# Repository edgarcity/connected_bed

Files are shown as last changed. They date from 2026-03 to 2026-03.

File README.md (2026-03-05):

# Lit Connecté — Réveil intelligent par détection de présence

Système de réveil anti-triche : si je ne suis pas levé 5 minutes après mon alarme, une alarme secondaire se déclenche et continue tant que je suis encore dans le lit. Impossible de tricher — 4 cellules de force sous les pieds du lit mesurent mon poids en continu.

## Comment ça marche

1. L'alarme iPhone sonne → un Raccourci Apple envoie automatiquement une requête HTTP à l'ESP8266
2. L'ESP8266 actionne un relais soudé sur la télécommande du rideau → le rideau se lève
3. Un décompte de 5 minutes démarre en tâche de fond
4. Si je suis encore dans le lit à 5 min → le DFPlayer Mini lance la musique depuis la carte SD
5. La musique s'arrête dès que je me lève

## Matériel

- ESP8266 (serveur web embarqué)
- 4 cellules de force 35 kg + amplificateur HX711
- DFPlayer Mini + carte SD
- Relais soudé sur la télécommande du rideau
- PCB fabriquée et soudée à la main
- Supports imprimés en 3D pour les cellules de force

## Contenu du dépôt

- `docs/` → documentation complète du projet (PDF)
- `code/` → firmware C++ pour ESP8266
- `3D/` → fichiers des pièces imprimées en 3D

## Résultats

- Utilisé quotidiennement, zéro faux positif depuis la mise en service
- Coût total < 35 €
- Intégration iOS native via Raccourci Apple, aucune application tierce

## Licence

[CC BY-NC 4.0](https://creativecommons.org/licenses/by-nc/4.0/) — Utilisation libre et modification autorisées, usage commercial interdit.

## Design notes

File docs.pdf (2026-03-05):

# LIT CONNECTÉ

Réveil intelligent par détection de présence

ESP8266 | Capteur de force | Impression 3D | Domotique | Home Automation

Présentation du projet

Contexte
J’ai deux alarmes sur mon téléphone. La première me réveille. Si je ne suis pas levé de mon lit au bout de 5 minutes, la deuxième alarme (celle du lit) se déclenche et continue de jouer tant que je suis encore couché. Impossible de tricher : les capteurs sous les pieds du lit savent exactement si je suis toujours là.

Solution développée
Quand mon alarme iPhone sonne, un Raccourci Apple envoie automatiquement une requête HTTP à l’ESP8266 qui héberge un serveur web local. Le microcontrôleur reçoit la commande, vérifie via les 4 capteurs de force que je suis bien dans le lit, actionne un relais soudé directement sur les contacts du bouton de la télécommande du rideau pour le lever, puis démarre un décompte de 5 minutes en tâche de fond. Si au bout de ces 5 minutes je suis encore couché, le DFPlayer Mini commence à jouer la musique depuis la carte SD et continue tant que je ne me suis pas levé.

Déroulement d’un réveil
- L’alarme iPhone sonne → le Raccourci Apple envoie la requête HTTP vers l’ESP8266
- L’ESP8266 actionne le relais soudé sur la télécommande du rideau → le rideau se lève
- Décompte de 5 minutes démarre en tâche de fond sur le microcontrôleur
- Levé avant 5 min : les capteurs détectent l’absence de poids → rien ne se passe
- Toujours dans le lit à 5 min : le DFPlayer Mini lance la musique depuis la carte SD
- La musique continue tant que je suis encore couché, s’arrête dès que je me lève

Installation physique

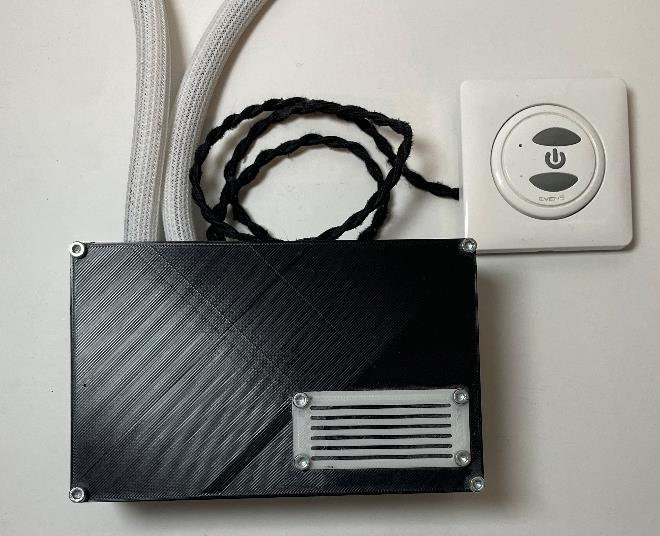
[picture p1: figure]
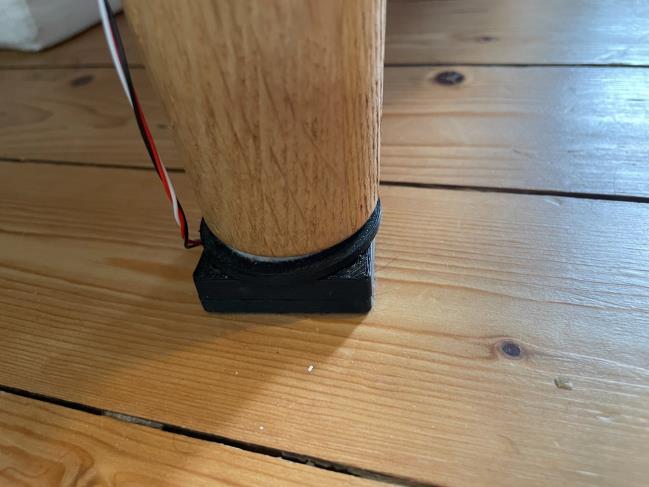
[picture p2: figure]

Boîtier ESP8266 et télécommande du rideau | Support cellule de force sous un pied du lit

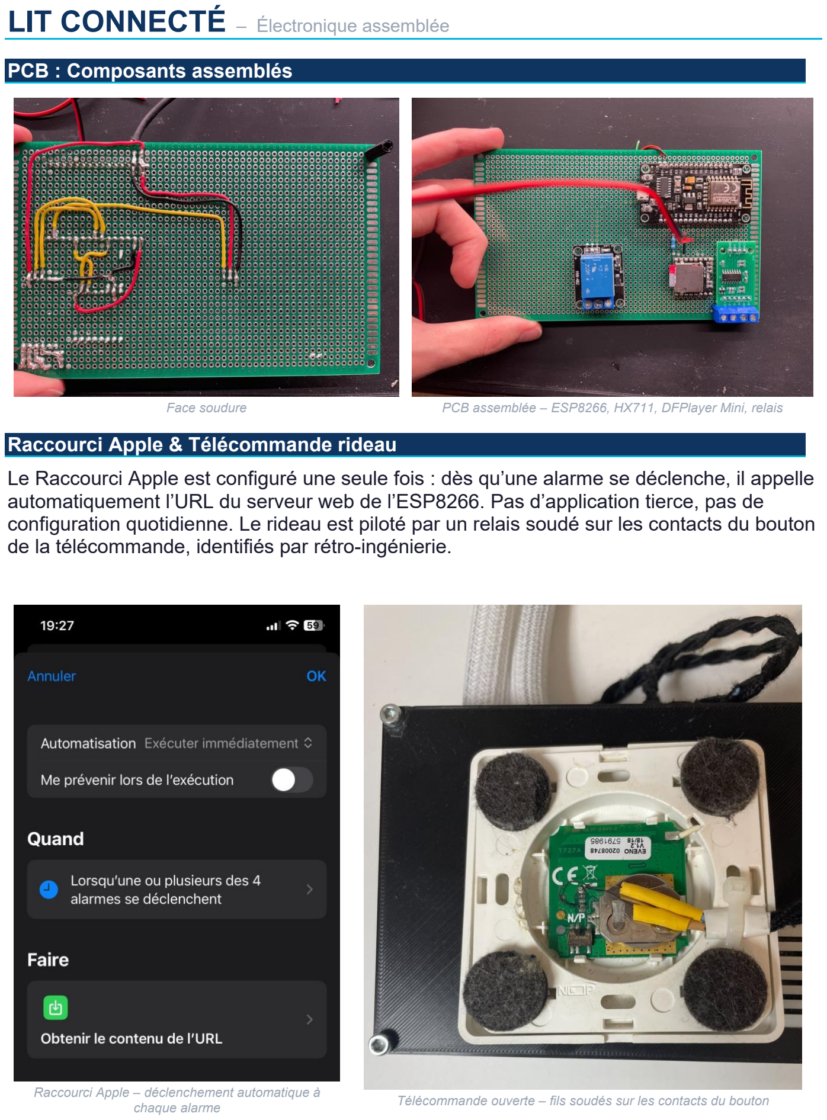
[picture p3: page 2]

LIT CONNECTÉ – Électronique assemblée

PCB : Composants assemblés

Face soudure | PCB assemblée – ESP8266, HX711, DFPlayer Mini, relais

Raccourci Apple & Télécommande rideau

Le Raccourci Apple est configuré une seule fois : dès qu’une alarme se déclenche, il appelle automatiquement l’URL du serveur web de l’ESP8266. Pas d’application tierce, pas de configuration quotidienne. Le rideau est piloté par un relais soudé sur les contacts du bouton de la télécommande, identifiés par rétro-ingénierie.

Raccourci Apple – déclenchement automatique à
chaque alarme | Télécommande ouverte – fils soudés sur les contacts du bouton

LIT CONNECTÉ – Cellules de force & Installation

Le choix du capteur : une décision clé

Le choix du capteur était l'étape la plus critique du projet : un faux négatif et je rate mon réveil, un faux positif et la musique ne tourne pour rien. Le FSR (pastille de pression sous le matelas) était l'option la plus simple, mais sa résistance dérive progressivement et les mouvements pendant le sommeil génèrent trop de bruit. La jauge de contrainte collée sur la structure du lit était plus précise, mais trop sensible aux variations de température et d'humidité pour être fiable sur la durée. La cellule de force s'est imposée : posée sous chaque pied, elle mesure un poids réel en kilogrammes, indépendamment de l'environnement. C'est invasif à l'installation, mais c'est la seule solution qui ne se trompe jamais.

Cellules de force & supports imprimés 3D

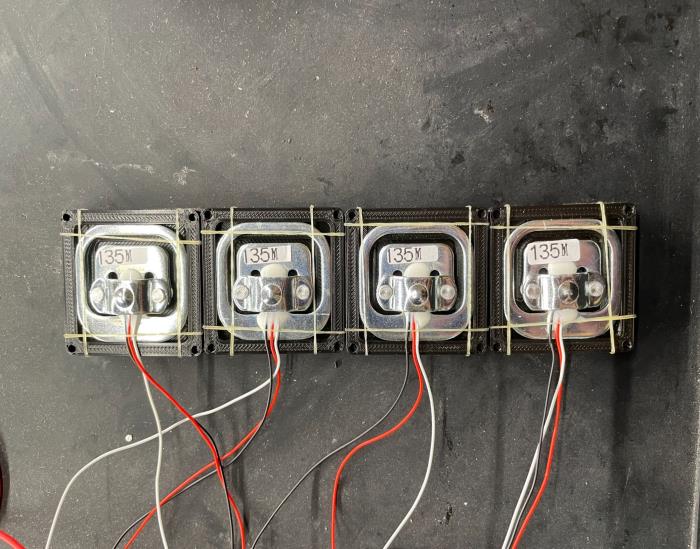
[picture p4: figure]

4 cellules de force 35 kg dans leur support imprimé 3D

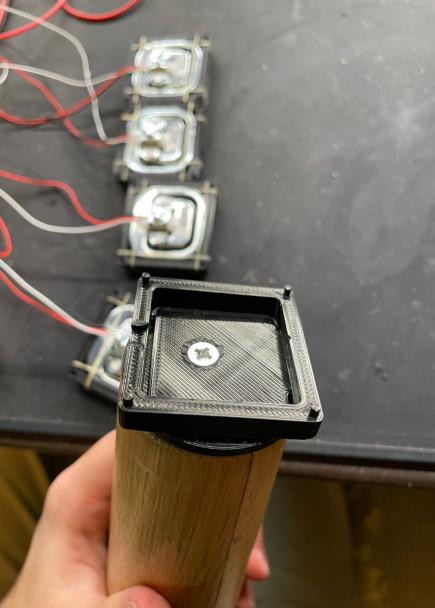
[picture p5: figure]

Support ouvert – logement capteur + vis de fixation

Résultats & Bilan

- Système fonctionnel et utilisé quotidiennement
- 4 cellules de force calibrées sur mon poids : le système ne s’est jamais trompé
- La deuxième alarme ne sonne que si je suis encore dans le lit
- Rideau connecté sans module domotique : relais soudé directement sur la télécommande existante
- Intégration transparente dans iOS : une seule configuration du Raccourci, zéro geste supplémentaire chaque soir
- Coût total < 35 € pour un résultat que les produits commerciaux ne proposent pas
- Compétences mobilisées : firmware C++ sur ESP8266, serveur web embarqué, rétro-ingénierie électronique, CAO & impression 3D, calibration de capteurs

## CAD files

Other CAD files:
3D/boîte de rangement.f3d
3D/capteur boîte.f3d

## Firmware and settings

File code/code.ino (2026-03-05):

#include <ESP8266WiFi.h> 
#include <ESP8266WebServer.h>
#include "HX711.h"
#include <SoftwareSerial.h>
#include <DFRobotDFPlayerMini.h>

// WiFi
const char* ssid = "Reseau YC";
const char* password = "classcroute01";

// Broches
#define RELAIS 5
#define DF_RX  13  // RX du DFPlayer (vers TX ESP8266)
#define DF_TX  2   // TX du DFPlayer (vers RX ESP8266)
#define DOUT 14    // HX711 Data (D5 sur NodeMCU)
#define SCK  12    // HX711 Clock (D6 sur NodeMCU)

// Seuils de poids
#define SEUIL_HAUT 50.0  
#define SEUIL_BAS 30.0   

ESP8266WebServer server(80);
HX711 balance;
SoftwareSerial mp3Serial(DF_RX, DF_TX);  
DFRobotDFPlayerMini dfPlayer;

float facteur_calibration = 11370.0;
float OFFSET_FIXE = 37.98;

unsigned long reveilTimestamp = 0;
bool attente15min = false;
bool musiqueActive = false;
bool surveillanceActive = false;
bool dejaLeve = false;

void handleRequest() {
    if (server.arg("action") == "rotate") {
        server.send(200, "text/plain", "Action effectuée !");
        yield();
        Serial.println("Activation du relais...");

        digitalWrite(RELAIS, HIGH);
        delay(500);
        digitalWrite(RELAIS, LOW);

        reveilTimestamp = millis();
        attente15min = true;  
        dejaLeve = false;
    }
}

void setup() {
    Serial.begin(115200);
    pinMode(RELAIS, OUTPUT);

    WiFi.begin(ssid, password);
    unsigned long wifiTimeout = millis();
    while (WiFi.status() != WL_CONNECTED && millis() - wifiTimeout < 30000) {
        delay(500);
        Serial.print(".");
    }
    if (WiFi.status() == WL_CONNECTED) {
        Serial.println("\nConnecté. IP: " + WiFi.localIP().toString());
    } else {
        Serial.println("\n⚠️ Échec de connexion Wi-Fi !");
    }

    server.on("/", handleRequest);
    server.begin();
    Serial.println("Serveur Web démarré.");

    balance.begin(DOUT, SCK);
    balance.set_scale(facteur_calibration);

    // Init DFPlayer Mini sur les nouvelles broches
    mp3Serial.begin(9600);
    if (!dfPlayer.begin(mp3Serial)) {
        Serial.println("⚠️ Erreur DFPlayer Mini !");
        while (true);
    }
    dfPlayer.volume(20);
}

void loop() {
    server.handleClient();
    
    float poids = (balance.get_units(10) - OFFSET_FIXE);
    Serial.print("Poids mesuré : ");
    Serial.println(poids);

    unsigned long elapsedTime = millis() - reveilTimestamp;

    // Déclenchement après 15 min
    if (attente15min && elapsedTime >= 900000) {  
        Serial.println("⏳ Temps écoulé : Vérification du lit.");
        attente15min = false;

        if (poids > SEUIL_HAUT) {
            musiqueActive = true;
            dfPlayer.loop(1);  // 🔥 Joue le fichier 1 en boucle
            Serial.println("🎵 Tu es encore au lit ! Musique activée.");
        }
    }

    // Arrêt de la musique quand l'utilisateur se lève
    if (musiqueActive && poids < SEUIL_BAS) {
        musiqueActive = false;
        dfPlayer.stop();
        dejaLeve = true;
        reveilTimestamp = millis();
        Serial.println("✅ Tu es levé, musique arrêtée.");
    }

    // Surveillance pendant 1h après le réveil
    if (dejaLeve && (millis() - reveilTimestamp <= 3600000)) {
        if (poids > SEUIL_HAUT && !musiqueActive) {
            musiqueActive = true;
            dfPlayer.loop(1);  // 🔥 Joue en boucle
            Serial.println("🎵 Tu es retourné au lit ! Musique réactivée.");
        }
    }
}

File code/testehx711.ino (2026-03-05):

#include <ESP8266WiFi.h>
#include <ESP8266WebServer.h>
#include "HX711.h"

// WiFi
const char* ssid = "Reseau YC";
const char* password = "classcroute01";

// Broches
#define RELAIS 5
#define BUZZER 4
#define DOUT 14  // GPIO14 (D5 sur NodeMCU)
#define SCK  12  // GPIO12 (D6 sur NodeMCU)

// Seuils de poids
#define SEUIL_HAUT 50.0  // Active le buzzer si poids > 50kg
#define SEUIL_BAS 30.0   // Désactive le buzzer si poids < 30kg

ESP8266WebServer server(80);
HX711 balance;
float facteur_calibration = 11370.0;
float OFFSET_FIXE = 24.11;
unsigned long reveilTimestamp = 0;
bool buzzerActif = false;
bool surveillanceActive = false;

// ✅ Fonction pour gérer la requête sans provoquer de déconnexion
void handleRequest() {
    if (server.arg("action") == "rotate") {
        server.send(200, "text/plain", "Action effectuée !"); // Répond immédiatement

        yield(); // ⚠️ Évite que le watchdog reset l'ESP8266
        Serial.println("Activation du relais...");
        
        digitalWrite(RELAIS, HIGH);
        delay(500);  // ⏳ Réduit le temps d’activation du relais pour éviter les coupures Wi-Fi
        digitalWrite(RELAIS, LOW);

        reveilTimestamp = millis();  // Enregistre l’heure du réveil
        surveillanceActive = true;

        delay(100); // 🛠️ Pause pour stabiliser la connexion après la réponse
    }
}

void setup() {
    Serial.begin(115200);
    pinMode(RELAIS, OUTPUT);
    pinMode(BUZZER, OUTPUT);
    digitalWrite(BUZZER, LOW);

    // ✅ WiFi avec timeout de 30s pour éviter une boucle infinie
    WiFi.begin(ssid, password);
    Serial.print("Connexion au WiFi...");
    unsigned long wifiTimeout = millis();
    while (WiFi.status() != WL_CONNECTED && millis() - wifiTimeout < 30000) {
        delay(500);
        Serial.print(".");
    }
    if (WiFi.status() == WL_CONNECTED) {
        Serial.println("\nConnecté. IP: " + WiFi.localIP().toString());
    } else {
        Serial.println("\n⚠️ Échec de connexion Wi-Fi !");
    }

    // Serveur Web
    server.on("/", handleRequest);
    server.begin();
    Serial.println("Serveur Web démarré.");

    // Initialisation du capteur HX711
    balance.begin(DOUT, SCK);
    balance.set_scale(facteur_calibration);
}

void loop() {
    server.handleClient();

    if (surveillanceActive && reveilTimestamp > 0) {
        unsigned long elapsedTime = millis() - reveilTimestamp;

        // Vérification après 15 minutes
        if (elapsedTime >= 30000) {
            float poids = (balance.get_units(10) - OFFSET_FIXE);
            Serial.print("Poids mesuré : ");
            Serial.println(poids);

            if (!buzzerActif && poids > SEUIL_HAUT) {
                buzzerActif = true;
                digitalWrite(BUZZER, HIGH);
                Serial.println("Tu es toujours au lit ! Buzzer activé.");
            } else if (buzzerActif && poids < SEUIL_BAS) {
                buzzerActif = false;
                digitalWrite(BUZZER, LOW);
                Serial.println("Tu es levé ! Buzzer désactivé.");
                reveilTimestamp = millis();  // Redémarre la surveillance pour 1 heure
            }
        }

        // Surveillance d'une heure après le lever
        if (!buzzerActif && (millis() - reveilTimestamp <= 3600000)) {
            float poids = (balance.get_units(10) - OFFSET_FIXE);
            Serial.print("Poids surveillé après lever : ");
            Serial.println(poids);

            if (poids > SEUIL_HAUT) {
                buzzerActif = true;
                digitalWrite(BUZZER, HIGH);
                Serial.println("Tu es retourné au lit ! Buzzer réactivé.");
            }
        }
    }
}
